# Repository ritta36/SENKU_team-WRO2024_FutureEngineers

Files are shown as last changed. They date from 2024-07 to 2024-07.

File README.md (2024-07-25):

<h1 style="background-color: rgba(200, 200, 200, 0.6)">SENKU-Team soulotion_Future Engineers WRO2024</h1>
<hr>

WRO

<p> We have solved the WRO2024 Future Engineers problem, and this repository details the development and design process of an autonomous vehicle created for participation in the WRO 2024 Future Engineers Category. The car represents a fusion of theoretical, mathematical, and mechanical engineering principles, combined with complex programming tasks and computer vision techniques. The repository provides a detailed explanation of the solution presented by the SENKU team. It includes all the steps we have undertaken in detail, along with the written codes, mechanical and electronic components used, and a comprehensive and detailed explanation of the algorithm. Additionally, it covers all the essential technical and mathematical fundamentals necessary to create the SENKU Robot vehicle and solve the problem, with the aim of providing a comprehensive information source for everyone.<p>

<p>Using this repository, a self-driving car can be built that is capable of completing three laps within the boundaries of the track, overcoming the obstacles present, and finally parking in a designated spot.<p>

## Content

* `t-photos` contains 2 photos of the team (an official one and one funny photo with all team members)
* `v-photos` contains 6 photos of the vehicle (from every side, from top and bottom)
* `video` contains two .md files with links to Youtube videos for each open challenge and obstacle challenge.
* `Engineering Journal` It includes a PDF file for documentation that contains a complete explanation of the solution, including descriptions of the components used, the algorithm, and more..
* `schemes` contains several schematic diagrams for electromechanical components used in the vehicle هn addition to the complete circuit schematic, it illustrates the components and how they connect to each other.
* `src` This directorycontain the codes used during the competition, as well as all other necessary codes for testing sensors, motors, and calibration.
* `models` is for the files for models used by 3D printers to produce the vehicle elements.
* `other` Here, we have included all the auxiliary folders that contain: flowcharts used for a clearer explanation of the followed algorithms, a pictures folder containing the images used in the repository, and finally, a <a href="https://github.com/ritta36/SENKU_team-WRO2024_FutureEngineers/blob/main/README.md#introduction">Software Setup.md</a> file that provides a comprehensive and sufficient explanation of how to set up the software, install necessary applications, download libraries, and more.
<h1>Introduction</h1>

<p1>The problem we have solved involves creating a self-driving car capable of completing laps within the boundaries of the track, overcoming colored obstacles based on their color, and finally parking in a designated area within the track. To achieve this, we used electronic components with functional capabilities that serve the solution, as well as mechanical techniques that aid in movement.

Regarding the codes, we used a Python code to capture images using a camera and process them to identify the locations and colors of the obstacles, and then send the information to the Arduino board. The Arduino board uses this information along with sensor readings, which are processed using Arduino C code, to control the motors' movements to correctly navigate the obstacles and complete the laps within the track.
This repository will explain the following:
<p1>

<h2>Contents of Readme file:</h2>

<dl>
  <dt><a href="https://github.com/ritta36/SENKU_team-WRO2024_FutureEngineers/blob/main/README.md#introduction">Introduction</a></dt>
  <dt><a href="https://github.com/ritta36/SENKU_team-WRO2024_FutureEngineers/blob/main/README.md#mobility-management">Mobility Management</a></dt>
  <dd><a href="https://github.com/ritta36/SENKU_team-WRO2024_FutureEngineers/blob/main/README.md#1-vehiclemainbody">-Vehicle Main Body</a></dd>
  <dd><a href="https://github.com/ritta36/SENKU_team-WRO2024_FutureEngineers/blob/main/README.md#2-motion-mechanism">-Motion Mechanism</a></dd>
  <dd><a href="https://github.com/ritta36/SENKU_team-WRO2024_FutureEngineers/blob/main/README.md#3-engineering-principles">-Engineering Principles</a></dd>

  <dt><a href="https://github.com/ritta36/SENKU_team-WRO2024_FutureEngineers/tree/blob/main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">Power and Sense Management</a></dt>
  <dd><a href="https://github.com/ritta36/SENKU_team-WRO2024_FutureEngineers/tree/blob/main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">-Electrical Parts</a></dd>
  <dd><a href="https://github.com/ritta36/SENKU_team-WRO2024_FutureEngineers/tree/blob/main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">-Overall Circuit Current Usage</a></dd>
  <dd><a href="https://github.com/ritta36/SENKU_team-WRO2024_FutureEngineers/tree/blob/main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">-Circuit Grounding</a></dd>
  <dd><a href="https://github.com/ritta36/SENKU_team-WRO2024_FutureEngineers/tree/blob/main?tab=readme-ov-file#4-power-supply">-Power Supply</a></dd>
  <dd><a href="https://github.com/ritta36/SENKU_team-WRO2024_FutureEngineers/blob/main/README.md#overall-scheme">-Overall Scheme</a></dd>
  
  <dt><a href="https://github.com/ritta36/SENKU_team-WRO2024_FutureEngineers/blob/main/README.md#obstacle-management">Obstacle Management</a></dt>
  <dd><a href="https://github.com/ritta36/SENKU_team-WRO2024_FutureEngineers/blob/main/README.md#1-open-challenge-algorithm">-Open Challenge Algorithm</a></dd>
  <dd><a href="https://github.com/ritta36/SENKU_team-WRO2024_FutureEngineers/blob/main/README.md#2-computer-vision">-Computer Vision</a></dd>
  <dd><a href="https://github.com/ritta36/SENKU_team-WRO2024_FutureEngineers/blob/main/README.md#3-image-processing">-Image Processing</a></dd>
  <dd><a href="https://github.com/ritta36/SENKU_team-WRO2024_FutureEngineers/blob/main/README.md#4-problems-we-encountered">-Problems We Encountered</a></dd>
  <dt><a href="https://github.com/ritta36/SENKU_team-WRO2024_FutureEngineers/blob/main/README.md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">Suggestions and Future Modifications</a></dt>
  <dd><a href="https://github.com/ritta36/SENKU_team-WRO2024_FutureEngineers/blob/main/README.md#1-open-challenge">-Open Challenge</a></dd>
  <dd><a href="https://github.com/ritta36/SENKU_team-WRO2024_FutureEngineers/blob/main/README.md#2-obstacle-challenge">-Obstacle Challenge</a></dd>
  <dd><a href="https://github.com/ritta36/SENKU_team-WRO2024_FutureEngineers/blob/main/README.md#3-differential">-Differential</a></dd>
  <dd><a href="https://github.com/ritta36/SENKU_team-WRO2024_FutureEngineers/blob/main/README.md#4-micro-controller-upgrade">-Micro-controller Upgrade</a></dd>
  <dd><a href="https://github.com/ritta36/SENKU_team-WRO2024_FutureEngineers/blob/main/README.md#5--sensor-upgrades">-Sensor Upgrades</a></dd>
  <dd><a href="https://github.com/ritta36/SENKU_team-WRO2024_FutureEngineers/blob/main/README.md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">-Power Management System (PMS)</a></dd>
  <dt><a href="https://github.com/ritta36/SENKU_team-WRO2024_FutureEngineers/blob/main/README.md#conclusion">Conclusion</a></dt>
  <dt><a href="https://github.com/ritta36/SENKU_team-WRO2024_FutureEngineers/blob/main/README.md#references">References</a></dt>
</dl>

<h2>Mobility Management</h2>

<h3>1-VEHICLEMAINBODY</h3>
<p>The main body of the vehicle was divided into two sections. The 3D printing section comprises four parts: the upper structure, two parts forming a camera holder, and the last part serving as a battery holder.<br> 
The second part of the structure is a chassis that features rear-wheel drive combined with a front steering mechanism, enabling it to turn both left and right. Also, it is made from aluminum which is a good material due to its lightness and durability.
The main microcontroller is an Atmega mounted on an Arduino Mega 2560 board. To ensure accurate and efficient control and direction of the vehicle’s movement, we employed several crucial components which are :
<br> • ServoMotorModel
<br> •  DC JSumo Motor 1000 RPM
<br> • BTSMotorDriver</p>
<p>The servo motor model was selected for controlling the vehicle’s steering, while the BTS7960 motor driver is utilized to control the movement of the DC motor, providing the necessary power to drive the vehicle’s motion.</p>

<h4>2-3D Printing parts</h4>
<p>We utilized SOLIDWORKS to design the components, followed by 3D printing these designs using PLA material. This process enabled us to create precise and customized parts for our robot, ensuring optimal performance and adherence to our design specifications. you can reach the 3D files in <a href="https://github.com/ritta36/SENKU_team-WRO2024_FutureEngineers/tree/main/models">this link.</a></p>

<b>Hexagonal Rod</b>
<p>The hexagonal rod is a key component, used for providing structural support in the assembly. It features a hollow center which allows for integration with other parts.</p>

<b>• Camera Holder</b>
<p>The camera holder is designed to securely hold the camera in place, ensuring stability and precision in positioning. It includes both parts of the holder and the complete assembly.</p>
<b>• Ultrasonic Sensor Holder Base</b>
<p>The ultrasonic sensor holder base is used to mount the ultrasonic sensor, providing a stable platform for accurate distance measurements.</p>
<b>• JSumo Tan Technic Gear 20 Tooth Double Bevel</b>
<p>This gear is a crucial component in the assembly, providing the necessary transmission of motion through its double bevel design.</p>
</li>
<b>• Battery Holder</b> The battery holder is designed to securely hold the battery in place, providing necessary power to the assembly. It is robustly built to ensure stability and easy replacement of batteries when needed.<br>
  <h3>3-Motion Mechanism.</h3>
  <p>We implemented Ackermann steering by installing a servo motor that allows the steering mechanism to operate freely. Additionally, a DC Jsumo motor with a 1000 rpm output acts as the propulsion motor. The kinetic energy produced by the Jsumo is conveyed to the rear wheels through a differential gearbox, and this energy is transmitted to the wheels via drive shafts constructed from LEGO components. Now we will explain both of the <b>Ackermann steering</b> and the <b>Differential gear:</b></p>
  <h4>1-Ackerman Steering Mechanism</h4>
  <p>Our design features an Ackermann steering mechanism, essential for providing efficient and responsive steering performance. The Ackermann steering principle is instrumental in minimizing tire wear and enhancing the vehicle's handling, especially during turns.</p>
   <p>The key features and benefits of the Ackermann steering is that it enhances maneuverability by reducing tire slippage during turns. This is achieved by configuring the steering linkages to allow the inner wheel to turn at a sharper angle than the outer wheel. Each wheel follows its own natural arc around the corner, leading to more precise steering and better vehicle control. Additionally, the Ackermann steering mechanism streamlines the overall design of the steering system. It eliminates the need for complex gear arrangements, which reduces weight and potential failure points within the system. This simpler design also leads to easier maintenance and lower manufacturing costs.</p>

<b>Working Mechanism of Ackermann Steering: </b>
<p>The functionality of the Ackermann steering system can be summarized as follows:</p>
<b>Steering Input Translation:</b> When the servo motor is activated, the input is conveyed through the steering linkage to both front wheels. The unique angles and lengths of the steering arms cause the inner wheel to turn more sharply than the outer wheel.<p>
<p><b>Cornering:</b> During cornering, the Ackermann geometry ensures that each wheel follows its respective path, minimizing slippage and enhancing the vehicle's grip on the playing field.</p>
<b>Key Parameters of Ackermann Steering</b>

<p><b>Steering Ratio:</b> In the Ackermann steering system, the steering ratio describes the relationship between the rotation of the servo angle and the resulting rotation of the wheels. It can be expressed mathematically as follows:</p>
<p>Steering Ratio = <span>&theta;<sub>Servo angle</sub></span> / <span>&theta;<sub>wheels</sub></span></p>

<p>A higher steering ratio means that a smaller rotation of the servo angle results in a larger rotation of the wheels, providing greater turning capability. Conversely, a lower steering ratio requires more rotation of the servo to achieve the same amount of wheel rotation, resulting in a less sensitive steering response.</p>
<b>Servo Motor Torque</b>
<p>Steering torque (T<sub>servo</sub>) is the force applied to the servo as a result of the torque output from the steering system. It is calculated by multiplying the applied force by the effective lever arm length (L<sub>eff</sub>):</p>
<p><strong>T<sub>servo</sub> = F<sub>steering</sub> × L<sub>eff</sub></strong></p>
<p>Higher servo motor torque indicates that more force is needed to turn the wheels, providing greater resistance to steering and a more stable driving experience.</p>
<b>Steering Wheel Angle</b>
<p>The steering wheel angle refers to the angular displacement of the steering wheel from its neutral position. This angle determines the orientation of the vehicle's steering mechanism and, consequently, its direction of movement:</p>
<p><strong>&theta;<sub>servo</sub> = &theta;<sub>servo angle</sub> × Steering Ratio</strong></p>
<p>Servo motor angle directly influences the turning radius of the vehicle, affecting its maneuverability and handling characteristics.</p>

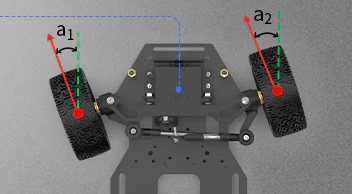
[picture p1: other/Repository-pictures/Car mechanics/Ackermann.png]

<br> 
    <figcaption>Figure 20: Ackermann steering principle.</figcaption>
  </figure>

<br> 
<br>
<h4>2-Differential Gear</h4>

<h4>Current Implementation and Challenges</h4>

<p>The differential gear is a vital component in our robot, ensuring that the rear wheels can spin at different rates while maintaining balanced power distribution. This mechanism is particularly crucial during turns or when traction varies between the two wheels, allowing for smooth and controlled movement. Here’s an overview of the differential gear system and its components:</p>

<strong>Components:</strong>
<ol>
    <li><strong>Ring Gear:</strong> This large gear, attached to the axle shaft, receives power from the engine or driveshaft.</li>
    <li><strong>Pinion Gear:</strong> A smaller gear that connects to the drive shaft and meshes with the ring gear.</li>
    <li><strong>Side Gears:</strong> Two gears that link the differential to the axle shafts.</li>
    <li><strong>Spider Gears:</strong> Positioned between the side gears, these gears permit the wheels to rotate at varying speeds.</li>
</ol>
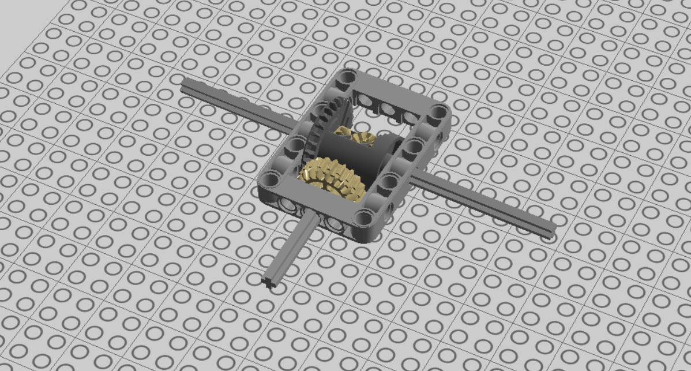
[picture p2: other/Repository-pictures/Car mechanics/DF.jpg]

<figcaption>Figure 21: Lego Differential Gear</figcaption>
</figure>
<br>
<br>
<strong>Functionality:</strong>
<p>When the vehicle travels in a straight line, the differential distributes torque equally to both wheels. During a turn, the inside wheel (closer to the center of the turn) needs to rotate slower than the outside wheel to prevent slippage. The differential achieves this by allowing the side gears to rotate at different speeds while still distributing power effectively.</p>

<strong>Calculating Gear Ratio:</strong>
<p>Before designing a differential gear, determining the gear ratio is crucial. This involves understanding the motor specifications and the differential’s mechanical setup. The gear ratio can be calculated by counting the teeth on the ring gear and the side gears:</p>

<p>$$ \text{GR} = \frac{R}{S1 + S2} $$</p>

<p>Where:</p>
<ul>
    <li><code>R</code> is the number of teeth on the ring gear.</li>
    <li><code>S1</code> and <code>S2</code> are the number of teeth on each side gear.</li>
</ul>

<p>This ratio indicates the rotational speed and torque distribution between the two side gears of the differential. Once calculated, this ratio helps relate the motor speed to the wheel speed. The wheel speed N<sub>wheel</sub> can be derived from the motor’s no-load speed <sup>N<sub>Motor, no-load</sub> using the formula:</p>

<p> $$ N_{\text{wheel}} = \frac{N_{\text{Motor, no-load}}}{\text{GR}} $$ </p>

<p>The wheel speed reflects the rotational speed of the differential’s side gears, directly influencing the vehicle’s speed. While theoretical calculations provide a baseline, real-world values often require calibration due to various unaccounted constraints.</p>

<h4>Suggestions and Future Modifications</h4>

<strong>Current Differential Issues:</strong>
<p>In our current design, we utilized a LEGO differential; however, we observed several shortcomings, specifically its low durability and the high flexibility of the LEGO axles.</p>

<strong>Recommended Differential Upgrade:</strong>
<p>To enhance the vehicle’s performance, we recommend using a metal differential with metal axles, which offer greater durability and reduced flexibility. This upgrade will ensure:</p>
<ul>
    <li><strong>Increased Durability:</strong> Metal differentials are more robust and can withstand higher stress and load without failing, ensuring longer operational life and reliability.</li>
    <li><strong>Reduced Flexibility:</strong> Metal axles are less flexible compared to LEGO axles, resulting in more precise and consistent power transmission to the wheels, improving overall vehicle control.</li>
</ul>

<strong>Impact on Vehicle Performance:</strong>
<ul>
    <li><strong>Enhanced Stability:</strong> The reduced flexibility and increased robustness of the metal components will provide greater stability, particularly during turns and when navigating uneven terrain.</li>
    <li><strong>Improved Power Transmission:</strong> The precise and consistent power transmission afforded by metal axles will enhance the vehicle’s responsiveness and maneuverability.</li>
    <li><strong>Long-Term Reliability:</strong> The durability of metal differentials ensures that the vehicle can operate under demanding conditions without frequent maintenance or replacement of parts.</li>
</ul>

<p>Implementing these modifications will significantly improve the vehicle's performance, making it more reliable and efficient in navigating the challenges of the competition.</p>

<h4> 3-Motor Driver</h4>
<p>A motor driver is an indispensable device in controlling motors because it allows the safe handling and delivery
of required power for driving the motor; at the same time, it includes protection features to guard against
damage under abnormal operating conditions. In addition, the motor driver provides accurate control, speed,
direction, and acceleration. A driver is a must for those applications that require precise positioning or motion
control, as in our case. It has bidirectional control, works with various motor types, and optimizes power usage
for more efficiency</p>

<figure>

  <br>
<figure >Figure 4: Basic-open loop control of motor speed</figcaption>
</figure>
<br>
<br> 

<h4>4- Wheels</h4>
<p>Wheels were used in the robot's design, their advantage comes from their efficiency and light weight. These wheels provide good friction, which enhances stability and maneuverability on various surfaces. [26]</p>
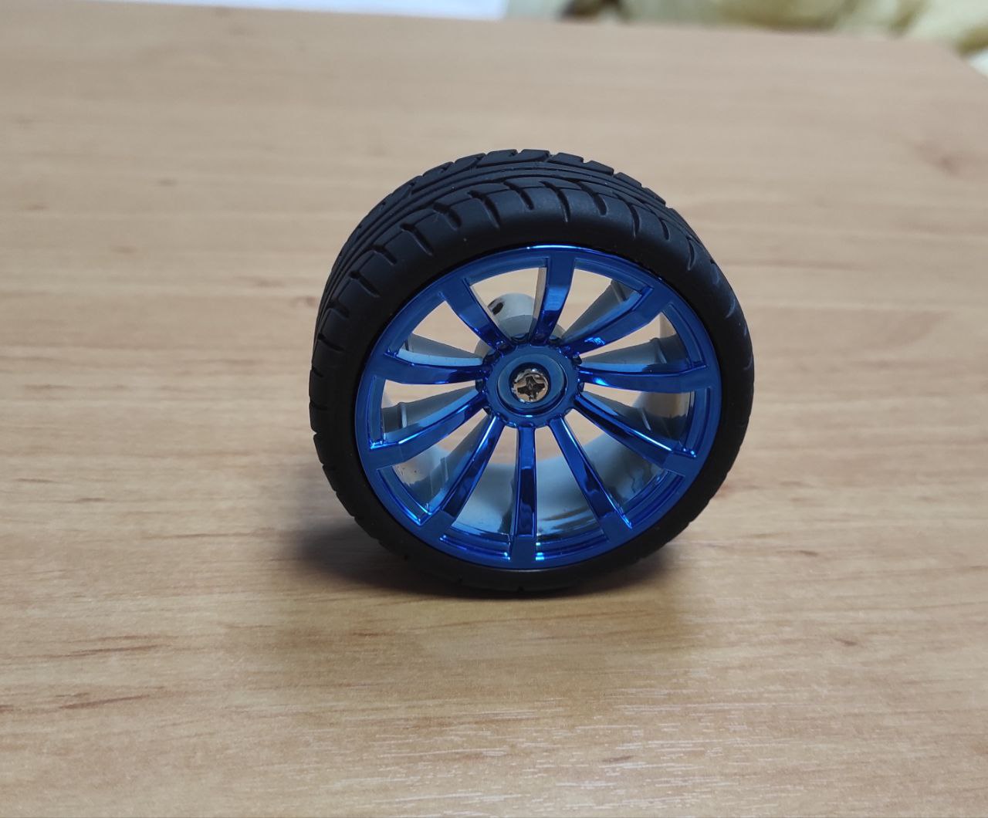
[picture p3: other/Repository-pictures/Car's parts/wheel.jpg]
Rubber Wheel

<caption><strong>Figure 23:</strong> Wheel</caption>
<table>
    <caption>Table 1: Specifications of 65mm Rubber Wheels</caption>
    <tr>
        <th>Specification</th>
        <th>Details</th>
    </tr>
    <tr>
        <td>Diameter</td>
        <td>65mm</td>
    </tr>
    <tr>
        <td>Width</td>
        <td>25-30mm</td>
    </tr>
    <tr>
        <td>Material</td>
        <td>Rubber tire with plastic or metal hub</td>
    </tr>
    <tr>
        <td>Axle Hole</td>
        <td>Compatible with standard hex couplings (often 4mm or 6mm)</td>
    </tr>
    <tr>
        <td>Coupling Type</td>
        <td>Lengthen copper coupling with hex connection</td>
    </tr>
    <tr>
        <td>Weight</td>
        <td>Usually light, suitable for small to medium-sized RC vehicles</td>
    </tr>
    <tr>
        <td>Use</td>
        <td>Suitable for DIY projects, Arduino smart car chassis, and other robotics applications</td>
    </tr>
</table>

<h4>5- Lego Axles</h4>
<p>Using the LEGO axles (4.8mm Diameter) on both the differential gears mechanism and the wheels connecting leads to a significant improvement in the robot's efficiency. The axles deliver accurate rotary motion while cutting down friction and energy losses. It is made of PA (Polyamide), which is a type of material that can withhold high loads and impacts. This means it is suitable for elements that have to be tough and can interact with each other, thus enabling a smooth power transmission of prolonged operation.</p>
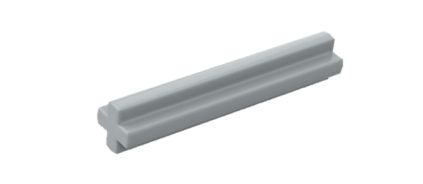
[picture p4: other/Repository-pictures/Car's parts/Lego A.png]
Lego Axle

<caption><strong>Figure 24:</strong> Lego Axle</caption>

<h3>3-Engineering Principles</h3>
  <p>The selection of materials and components for our vehicle was guided by several key engineering principles:</p>
  <ul>
    <li><strong>Torque and Speed Calculations:</strong> The motors were chosen based on the required torque to overcome friction and inertia, ensuring sufficient speed for the competition.</li>
    <li><strong>Material Selection:</strong> Aluminum was selected for its strength-to-weight ratio, providing a lightweight yet durable structure.</li>
    <li><strong>3D Printing Selection:</strong> PLA is easy of Printing, Strength and aligns with sustainable engineering practices, making it an eco-friendly choice.</li>
    
  </ul>
<h2>Power and Sense Management</h2>

 <h3>1-Electrical Parts</h3>
    <section>
        <b>Section 2, Subsection 1</b>
        <ol>
            <li>
                <strong>Arduino Mega 2560:</strong>
                <ul>
                    <li>Microcontroller: ATmega2560</li>
                    <li>Features: 54 digital I/O pins, 16 analog inputs, USB interface, operates at 5V</li>
                    <li>Used for complex and resource-intensive projects due to ample processing power and memory.</li>
                </ul>
            </li>
            <li>
                <strong>Arduino Sensor Shield v2.0:</strong>
                <ul>
                    <li>Designed for Arduino Mega 2560</li>
                    <li>Features: Easy connection for sensors and modules, supports I2C, UART, and analog interfaces</li>
                    <li>Provides convenience and flexibility in connecting multiple components to the Arduino board.</li>
                </ul>
            </li>
            <li>
                <strong>Raspberry Pi 4 Model B:</strong>
                <ul>
                    <li>Processor: Broadcom BCM2711, quad-core Cortex-A72</li>
                    <li>Features: Dual micro HDMI ports, wireless LAN, Bluetooth 5.0, USB 3.0, up to 8GB RAM</li>
                    <li>Suitable for projects requiring substantial processing power and connectivity.</li>
                </ul>
            </li>
            <li>
                <strong>Cooling Fan:</strong>
                <ul>
                    <li>Used to reduce overheating in Raspberry Pi and enhance CPU performance</li>
                    <li>Essential for maintaining optimal operating temperatures and prolonging the lifespan of the device.</li>
                </ul>
            </li>
            <li>
                <strong>Raspberry Camera Module 3 (75 degrees FoV):</strong>
                <ul>
                    <li>Sensor: Sony IMX708, 11.9 Megapixels</li>
                    <li>Features: Motorized focus, wide field of view suitable for detecting obstacles and ensuring effective image processing.</li>
                </ul>
            </li>
            <li>
                <strong>BTS7960 Motor Driver:</strong>
                <ul>
                    <li>H-Bridge configuration, supports motors between 5V and 27V</li>
                    <li>Features: current sensing and protection against overcurrent and overtemperature</li>
                    <li>Useful in robotics for precise motor control.</li>
                </ul>
            </li>
            <li>
                <strong>XL4005 DC-DC Step-Down Converter:</strong>
                <ul>
                    <li>Input: 5V to 32V, Output: Adjustable from 0.8V to 30V, up to 5A current</li>
                    <li>High efficiency and includes features like thermal shutdown and short circuit protection</li>
                    <li>Converts high voltage to a lower voltage while maintaining high efficiency.</li>
                </ul>
            </li>
            <li>
                <strong>TowerPro MG996R Servo:</strong>
                <ul>
                    <li>High torque with metal gears, operates from 4.8V to 7.2V</li>
                    <li>Provides precise control suitable for robotics applications requiring robust actuation.</li>
                </ul>
            </li>
            <li>
                <strong>Li-Poly RC Battery:</strong>
                <ul>
                    <li>11.1V, 2700mAh with a 35C discharge rate</li>
                    <li>Provides high power and efficiency for demanding applications like RC vehicles.</li>
                </ul>
            </li>
            <li>
                <strong>JSumo 1000 RPM Motor:</strong>
                <ul>
                    <li>12V operation, 1000 RPM no-load speed</li>
                    <li>High power motor, ideal for robotics and sumo robot competitions.</li>
                </ul>
            </li>
            <li>
                <strong>MPU-6050 Sensor:</strong>
                <ul>
                    <li>Combined 3-axis gyroscope and accelerometer</li>
                    <li>Useful for motion sensing and orientation tracking in robotics.</li>
                </ul>
            </li>
            <li>
                <strong>HC-SR04 Ultrasonic Sensor:</strong>
                <ul>
                    <li>Measures distance using ultrasonic waves</li>
                    <li>Employed in robotics for obstacle detection and navigation.</li>
                </ul>
            </li>
        </ol>
    </section>

<h3> 2-Overall Circuit Current Usage</h3>
 <p> here are many reasons why it is important to have an accurate knowledge of the electrical component requirements which include</p>
    <ol>
        <li>
            <strong>Dual Mode (Operational and Sleep):</strong>
            <p>The power supply system is programmed to handle different current requirements when the robot is active (Operational) and when it is in a power-saving mode (Sleep). This helps in ensuring that the robot operates efficiently without draining unnecessary power when not performing intensive tasks.</p>
        </li>
        <li>
            <strong>Optimize for Battery Life:</strong>
            <p>Understanding the power consumption of each component is essential for optimizing battery life. By analyzing the current draw in various operational states, strategies can be developed to extend battery life, such as selecting the appropriate batteries and implementing power-saving modes.</p>
        </li>
        <li>
            <strong>Heat Management:</strong>
            <p>The total current load on a circuit contributes to the amount of heat generated by electrical components. Knowing this helps in designing effective cooling measures, which are crucial for preventing overheating that could lead to performance degradation or hardware damage.</p>
        </li>
        <li>
            <strong>Safety:</strong>
            <p>Accurate knowledge of the maximum current that each component draws is essential for designing a safe electrical system. This includes ensuring that all components can handle the peak currents under load without risk of electrical failures or hazards.</p>
        </li>
        <li>
            <strong>Cost Efficiency:</strong>
            <p>By understanding the exact power needs of each component, more cost-effective components and systems that meet the necessary specifications without excess can be selected.</p>
        </li>
    </ol>

<h3>3-Circuit Grounding</h3>
    <p>Circuit grounding connects all components with a common ground, providing a reference point for all voltages in the circuit and dramatically simplifying the measurement of voltage at any point in the circuit. It ensures the signal moves accurately without distortion, prevents electrical shocks, and safeguards the equipment, as well as people, from hazards that can arise otherwise.</p>
    <p>Grounding reduces electromagnetic interference (EMI) and radio frequency interference (RFI) by allowing a path for unwanted currents to dissipate harmlessly into the ground. This can greatly improve the performance and overall reliability of the circuit. Grounding stabilizes the voltage levels, preventing voltage fluctuation by ensuring a consistent electrical potential across all components. It may also help in reducing some noise and interference within the circuit. When several sections of the circuit share a common reference point, one can better filter noise and interference.</p>

  <h3>4-Power Supply</h3>
    <p>In the revised setup, an 11.1V – 2700mAh 35C Li-Poly RC battery is used as the power source, which directly provides 11.1V to both the BTS motor driver and the RioRand step-down DC-DC converter. The converter adjusts the voltage from 11.1V down to 5V to power the Arduino board. Additionally, the Arduino Sensor Shield, which conveniently offers the GND and VCC pins for connecting ultrasonic sensors, a servo motor, and a gyroscope without the need for a bridge or extra pins. This configuration results in a visually pleasing circuit that provides easy access to all pins and simplifies the troubleshooting of faults and issues. The DC motor receives power directly from the battery through the BTS motor driver, maintaining the supply at 11.1 volts.</p>

  <h3>5-Overall Scheme</h3>
    <p>Due to the large number of electronic components used in our circuit, we utilized a special power supply distribution using basic electronic components. The description below provides an overview of the electrical design:</p>
 
<br>
<br>
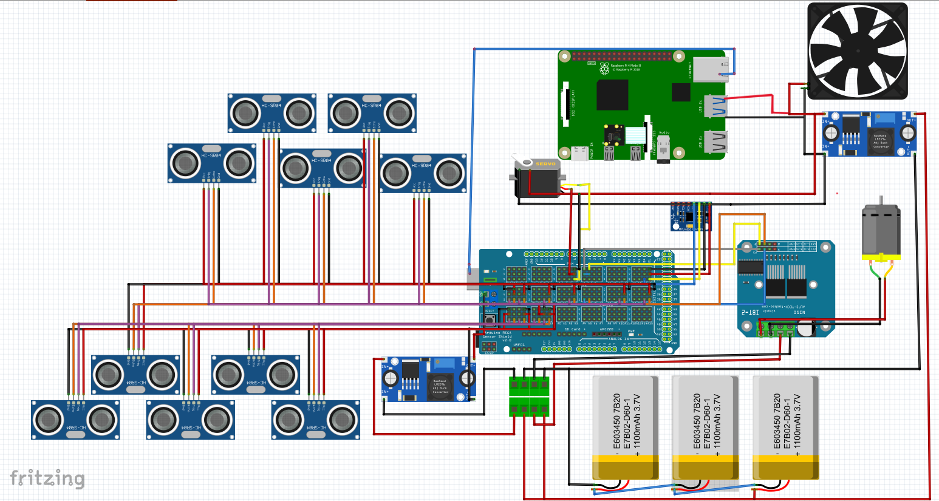
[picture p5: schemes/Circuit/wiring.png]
wiring managment

<caption><strong>Figure 25:</strong> The Circuit Wiring.</caption>
<br>
<br>
<br> 
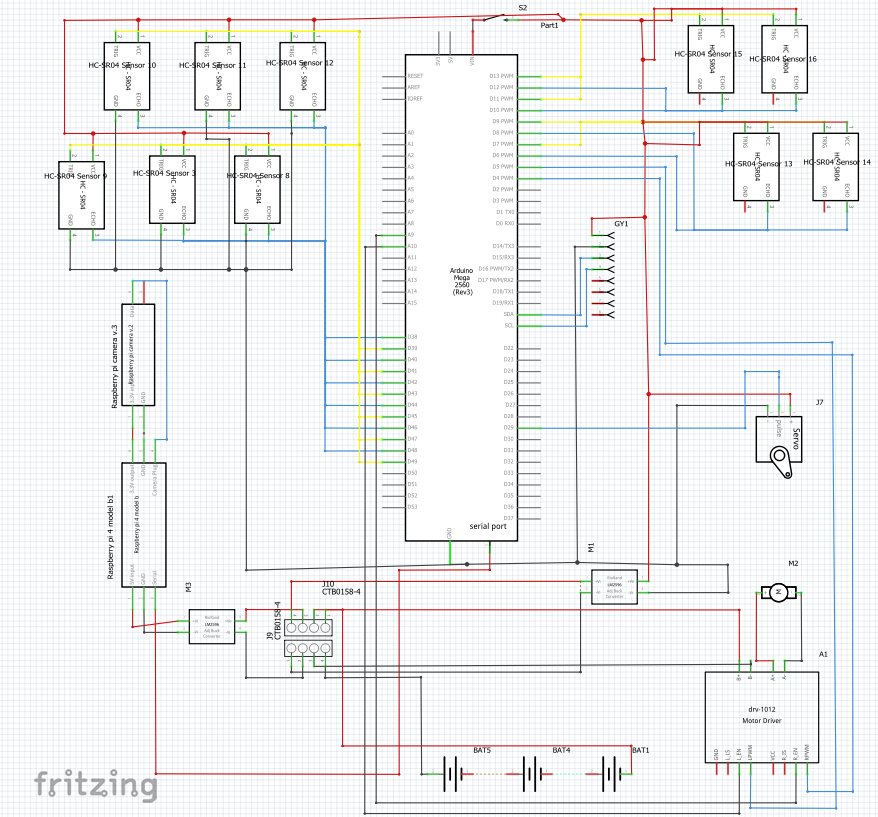
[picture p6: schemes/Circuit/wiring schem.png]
wiring schem

<br>
<caption><strong>Figure 26:</strong> The Circuit Wiring Diagram.</caption>
<br>

<h2>Obstacle Management</h2>

<h3>1-Open Challenge Algorithm</h3>
<p>In this section, we detail our approach for the Open Challenge, where the goal is to complete three laps while avoiding collisions with the track walls and achieving the fastest possible time. Our strategy involves designing a robust algorithm that ensures precise navigation and smooth transitions between different segments of the track. The track is divided into two primary zones: the Safe Zone and the Danger Zone, each requiring distinct handling strategies.</p>
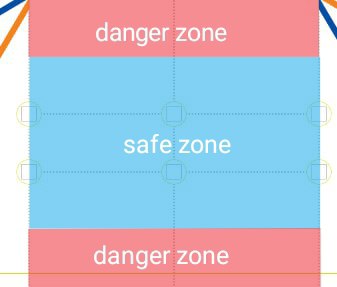
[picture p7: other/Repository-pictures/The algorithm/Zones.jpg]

<figcaption>Figure 27: zones Division
</figcaption>
</figure>
<h4> Safe Zone Navigation</h4>
<p>In the Safe Zone, the robot can move safely without the risk of colliding with the wall. The robot should maintain a straight path parallel to the wall. This is managed using a PD (Proportional-Derivative) controller that keeps the robot's angle constant. The gyroscope readings are used as inputs to the algorithm, and the setpoint is adjusted after each turn. The PD controller formula used is:</p>
<pre>PIDOutput = K_p &times; Error_t + (Error_t - Error_{t-1}) / IntervalLength &times; K_d</pre>
<p>Where:</p>

  <li><i>Error_t = GyroscopeReading - SetPoint</i></li>

<h4> Danger Zone Handling</h4>
<p>When the robot enters the Danger Zone, immediate corrective action is required to move it back to the Safe Zone. For this, we employ a P (Proportional) controller with a high proportional gain:</p>
<pre>ServoAngle = K_p &times; (D_{vertical} - D_{unprotected})</pre>
<p>Where:</p>

  <li><i>D_{vertical} = cos(Angle) &times; DS1 + DS2 / S2</i></li>

<h4> Turn Detection and Direction Control</h4>
<p>The robot detects turns at distances greater than 100 cm. If it cannot align parallel to the wall, incorrect ultrasonic readings might occur. In such cases, the robot uses its front ultrasonic sensor to detect the front wall and, if a safe turn is not possible, it moves backward until a safe turn can be made. The robot determines the movement direction (clockwise or counterclockwise) based on which side the turn is detected.</p>

<p>Overall, this algorithm ensures the robot navigates efficiently through the track, handling turns and zones with precise control to achieve the fastest lap times possible.</p>

<figcaption>Figure 28: Open challenge flowchart
</figcaption>
</figure>

<hr>

  <h3>2-Computer Vision</h3>
    <p>Computer vision is a fundamental technology in robotics and automation, crucial for enabling self-driving cars to perceive and interpret their surroundings. In our project, computer vision (CV) techniques empower the robotic system to gather essential information, facilitating informed decision-making and immediate actions. The identification of the pink
 parking, red and green pillars is critical for collision avoidance and maintaining a clear path for the robot.</p>
    
   <p>We employ the HSV (Hue, Saturation, Value) color space for color detection due to its robustness under varying lighting conditions. Unlike other color spaces such as RGB (Red, Green, Blue) or HSL (Hue, Saturation, Lightness), HSV separates color information (hue) from luminance, enhancing its reliability.</p>
    
  <b>HSV Color Space</b>
    <ul>
        <li><strong>Hue:</strong> Represents the type of color, measured as an angle in degrees (0-360), where red = 0, green = 120, blue = 240.</li>
        <li><strong>Saturation:</strong> Indicates the vibrancy of the color, ranging from 0 (gray) to 100 (full color).</li>
        <li><strong>Value:</strong> Defines the brightness of the color, with 0 as black (no brightness) and 100 as fully bright.</li>
    </ul>
    
  <b>Advantages of HSV over RGB for Color Detection</b>
    <ul>
        <li><strong>Decomposition of Color and Luminance:</strong> HSV effectively separates hue from saturation and value, making hue less affected by lighting changes and enabling more accurate region detection. RGB combines intensity with colors, complicating the appearance of hues under varying light.</li>
        <li><strong>Improved Color Filtering:</strong> HSV filters colors based on human perception, making it easier to isolate specific hues. In contrast, RGB colors can vary significantly with brightness changes.</li>
        <li><strong>Lighting Robustness:</strong> HSV is more resilient to lighting variations, as changes in light intensity affect hue less than in RGB, allowing for consistent color matching.</li>
    </ul>

   <p>Using HSV for computer vision in our project enhances the accuracy and reliability of color detection, crucial for the robot's autonomous navigation and obstacle avoidance.</p>
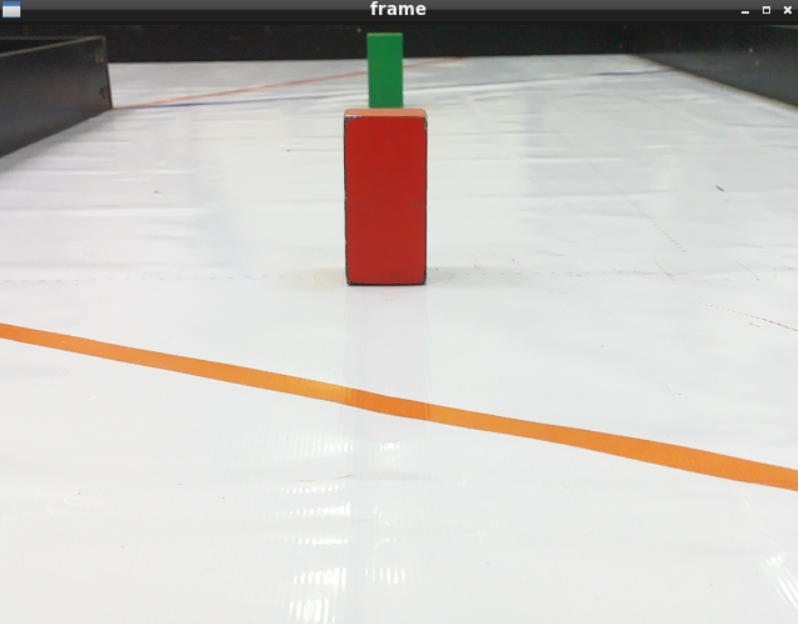
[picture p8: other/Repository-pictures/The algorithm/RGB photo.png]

<br>
<figcaption>Figure 29: RGB photo 
</figcaption>
</figure>
<br>
<br>
  <br> 
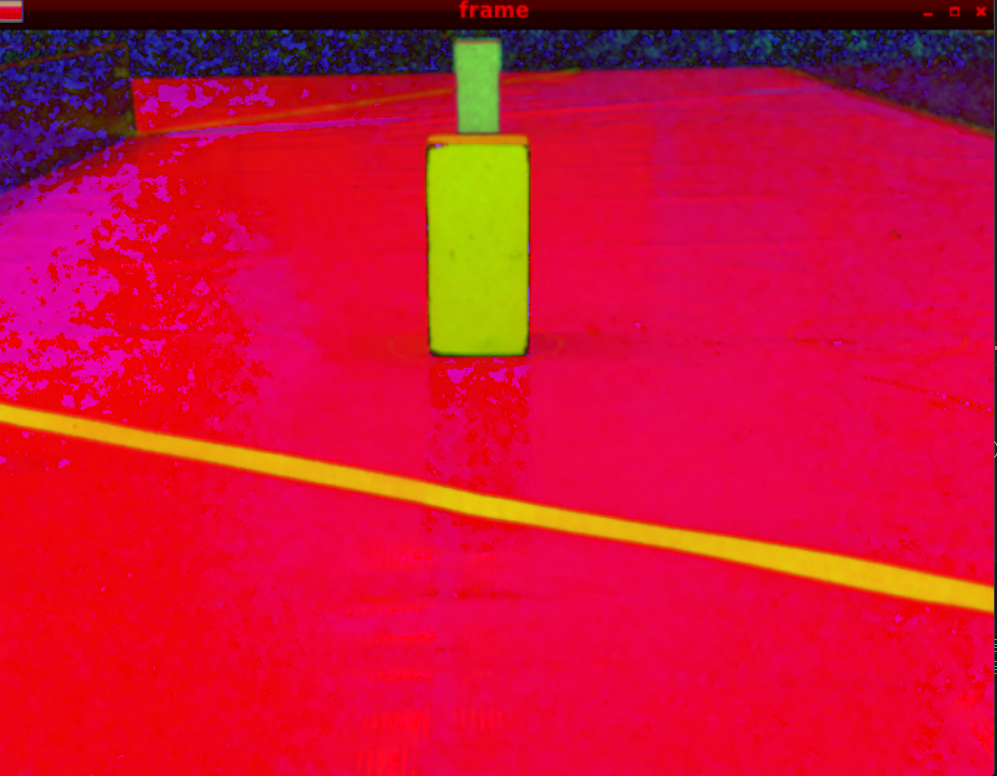
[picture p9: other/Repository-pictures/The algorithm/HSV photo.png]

<br>
<figcaption>Figure 30: HSV photo
</figcaption>
</figure>
<br>
<br>
<br>

<h3>3-Image Processing</h3>

  <h4>Setting the Camera Properties</h4>
    <p>The camera's shutter speed is adjusted according to the ambient lighting conditions. Shutter speed defines the duration for which the camera’s shutter remains open, allowing light to reach the camera sensor. In high-brightness environments, we reduce the shutter speed to limit the amount of light hitting the sensor during the calibration of HSV values. Conversely, in low-light conditions, we increase the shutter speed to allow more light to reach the sensor.</p>

  <h4>Pre-Processing</h4>
    <p>Pre-processing is essential before isolating the pillars to extract information. This step involves cleaning the captured images to remove unwanted artifacts, ensuring more accurate and reliable segmentation results. Cropping the frame removes distracting elements that might be mistaken for pillars.</p>

  <h4>Masking</h4>
    <p>To isolate specific colors, the image is first converted from the BGR color space to the HSV color space. We then identify the upper and lower HSV values of the target colors (red, green, or pink). Each pixel in the HSV frame is examined to determine if it falls within the specified color range. If it does, the corresponding pixel value in the mask will be white; otherwise, it will be black. The resulting mask frame will display white pixels for the desired color range and black pixels for all other colors.</p>

  <p>Our HSV values:</p>
    <ul>
        <li><strong>Red1:</strong> Lower value: [], Upper value: []</li>
        <li><strong>Red2:</strong> Lower value: [], Upper value: []</li>
        <li><strong>Green:</strong> Lower value: [], Upper value: []</li>
        <li><strong>Pink:</strong> Lower value: [], Upper value: []</li>
    </ul>
    <p>Note: HSV values may vary under different lighting conditions.</p>

| Original Frame | Mask | Result |
|---|---|---|
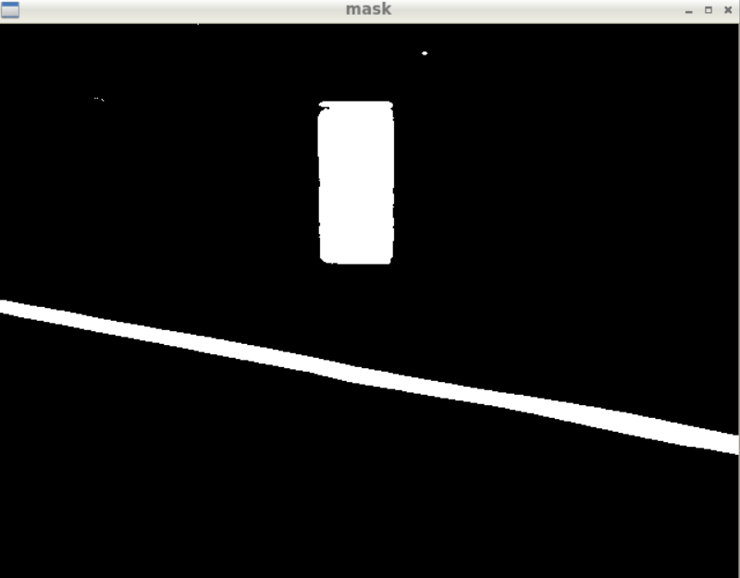
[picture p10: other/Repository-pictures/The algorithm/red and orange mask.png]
Mask Red 1
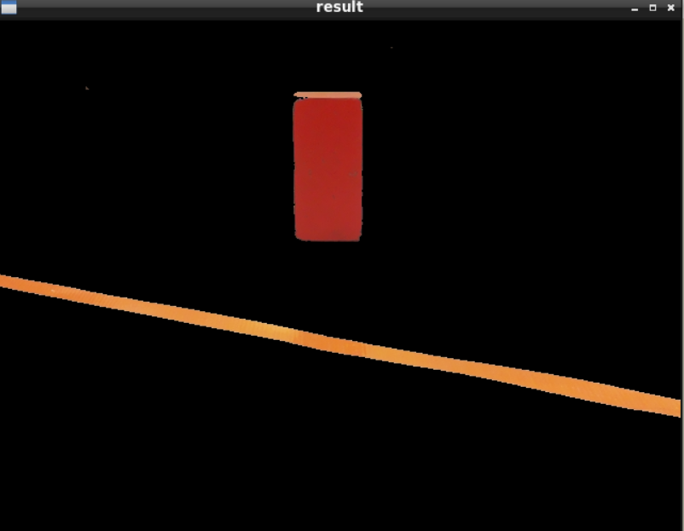
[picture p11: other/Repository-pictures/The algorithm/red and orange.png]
| Original Frame Red 1 |  |  |
| **Original Frame** | **Mask** | **Result** |
| **Figure 31: Red 1 Mask Analysis** |

| Original Frame | Mask | Result |
|---|---|---|
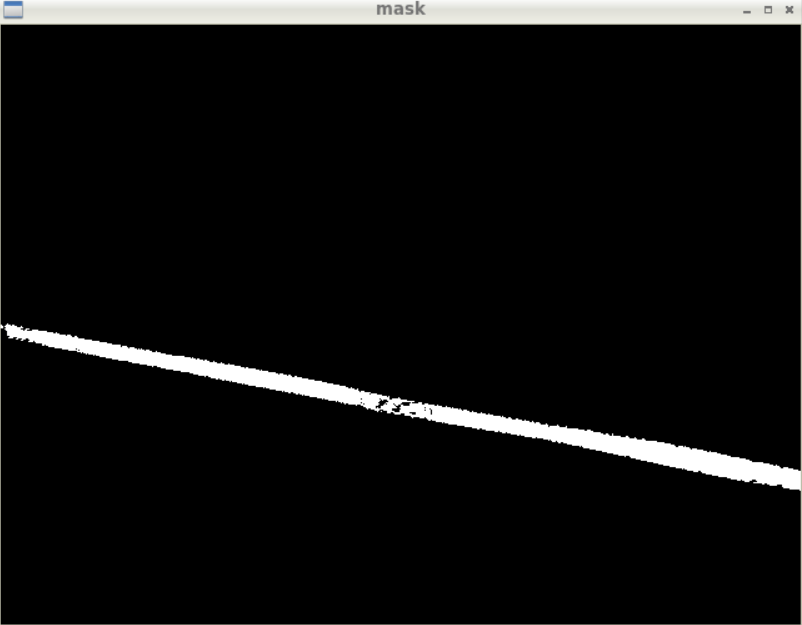
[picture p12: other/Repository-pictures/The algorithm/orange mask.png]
Mask Red 1
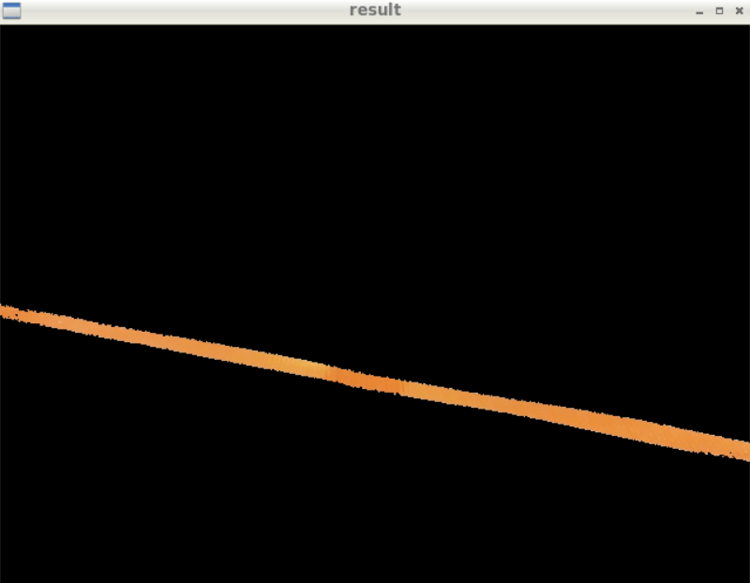
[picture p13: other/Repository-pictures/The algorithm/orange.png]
| Original Frame Red 2 |  |  |
| **Original Frame** | **Mask** | **Result** |
| **Figure 32: Red 2 Mask Analysis** |

| Original Frame | Mask | Result |
|---|---|---|
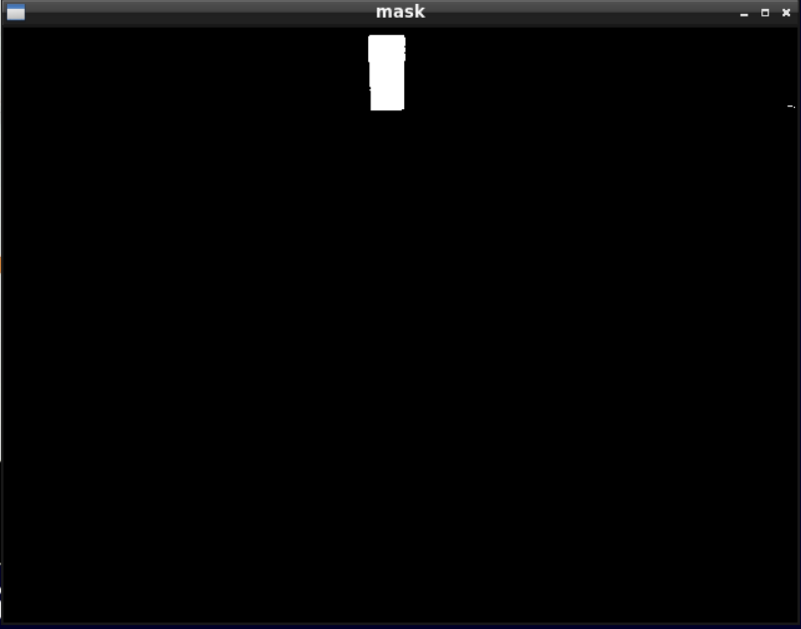
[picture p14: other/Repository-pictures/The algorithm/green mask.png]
Mask Red 2
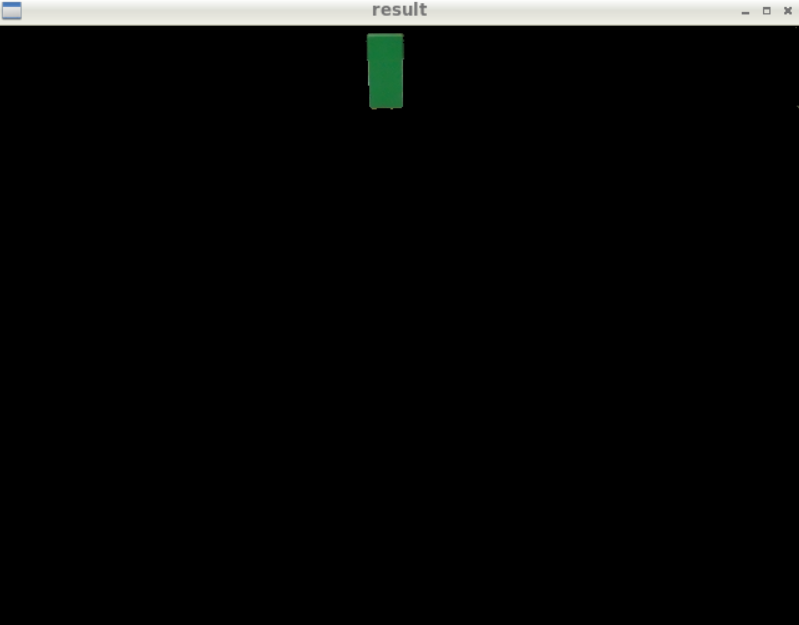
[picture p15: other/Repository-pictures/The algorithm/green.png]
Result Red 2
| Original Frame Green |  |  |
| **Original Frame** | **Mask** | **Result** |
| **Figure 33: Green Mask Analysis** |

  <h4>Contouring</h4>
    <p>Contour detection is the process of identifying the boundaries or edges of objects within an image. This process is fundamental to many image analysis applications, including image segmentation, object recognition, and classification.</p>
    <br>
<br>
<figcaption>Figure 34: Contouring Process
</figcaption>
</figure>
<br>
<br>

   <p><strong>Steps in the Contouring Process:</strong></p>
    <ol>
        <li>Finding the Contour Area:
            <pre>cv2.contourArea(contour)</pre>
        </li>
        <li>Finding the Bounding Rectangle:
            <pre>cv2.boundingRect(contour)</pre>
        </li>
        <li>Finding the Moment:
            <pre>cv2.moments(contour)</pre>
        </li>
        <li>Calculating Distance: The distance is calculated using a formula derived by plotting a curve between the actual distance and the contour area.</li>
    </ol>
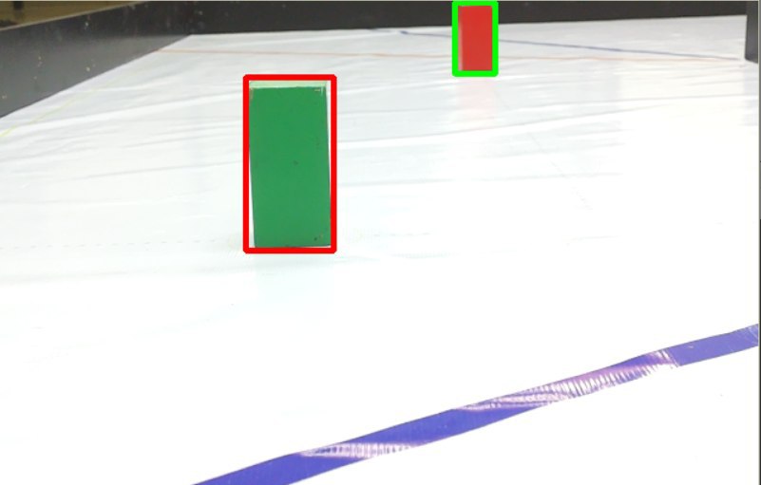
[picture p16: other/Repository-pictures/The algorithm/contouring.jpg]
Contouring Analysis

<strong>Figure 30: Contouring Analysis</strong>

  <h4>Our Algorithm to Avoid the Pillars</h4>
    <p>At the start of each section, the Raspberry Pi captures an image using the camera. It processes the image and applies a mask to detect any pillars in front of the vehicle. If a pillar is detected and the distance is less than 50 cm, the Raspberry Pi sends a signal to the Arduino ('G' for a green pillar, 'R' for a red pillar, and 'N' for no pillar). The Arduino then decides the course of action: turn left for 'G', turn right for 'R', or move forward for 'N'.</p>

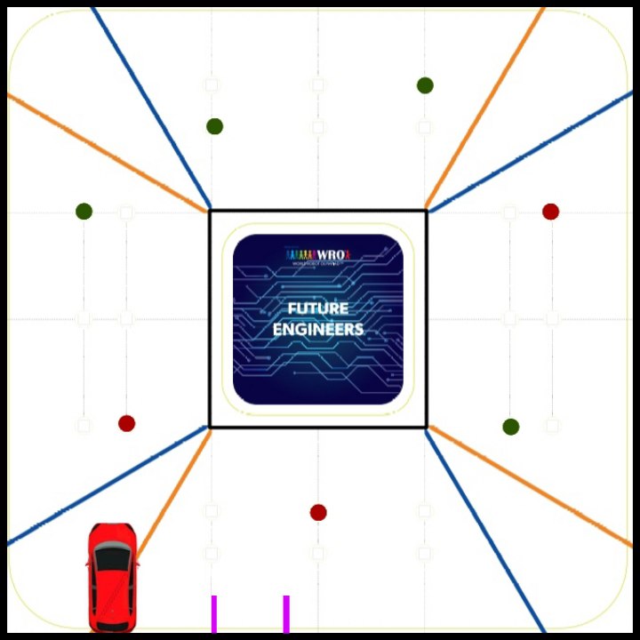
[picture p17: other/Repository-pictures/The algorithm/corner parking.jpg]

<br>
<figcaption>Figure 32:  the vehicle parking in the corner
</figcaption>
</figure>
<br>
<br>

<p>When the vehicle reaches a corner, the Arduino determines the direction of movement and communicates this to the Raspberry Pi ('L' for counterclockwise and 'R' for clockwise). At the end of each section, the Arduino sends a 'Hello' message to the Raspberry Pi, prompting it to take an image, process it, and report the current status back to the Arduino. The possible status cases are GG, G, RR, R, RG, and GR.</p>

<h3>4-Problems We Encountered</h3>

  <h4>Wave Interference</h4>
    <p>When two sensors on the same side of the robot operate simultaneously, the sound waves they emit can interfere with each other. To address this issue, we implemented a method where only sensors on opposite sides operate at any given time while the other sensors are disabled. Specifically, we take readings sequentially from R1 and L2, then R2 and L1, followed by F and B. This approach prevents wave interference during distance measurements.</p>

  <h4>Small Turn Angle and Sliding</h4>
    <p>Initially, the robot experienced issues with a small turn angle and sliding, primarily due to the absence of a differential gear. This caused the robot to require a large distance to achieve the desired turn angle, and the front tires often slipped. We resolved these problems by integrating a differential gear, which enhanced the turning capability and stability of the robot.</p>

  <h4>Flickering</h4>
    <p>Flickering refers to the visible fluctuation in brightness or color in video frames, which can occur rapidly and intermittently. We encountered this issue with the Raspberry Pi 4 and Camera Module 3 setup. Flickering can make the video output appear unstable and less effective for its intended use. We resolved this by adjusting the camera's shutter speed:</p>

   <pre>picam2.set_controls({"ExposureTime": shutter_speed})</pre>

  <p>This adjustment stabilized the video output, ensuring reliable performance for image processing tasks.</p>

  <h2> Suggestions and future modifications</h2>

  <h3>1-Open Challenge</h3>
  <p>
    Sometimes, the use of a gyroscope sensor can result in incorrect setpoint calculation. There is evidence for this in that after the robot has turned, it may not be turned precisely 90 degrees, maybe less or more. So, a correction formula is applied that corrects the reading from the gyro and calculates the correct set point.
  </p>
  <p><strong>Angle Calculation Formula:</strong> Angle = atan<sup>-1</sup>((DS1 - DS2) / DS1S2)</p>
<br>
  <figure>
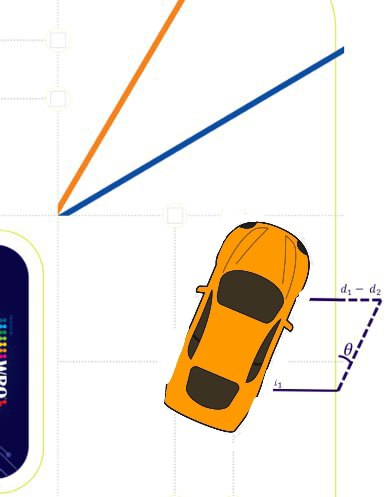
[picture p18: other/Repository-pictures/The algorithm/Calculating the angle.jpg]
Diagram showing angle calculation
    
    <br> 
    <figcaption>Figure 33: Angle Calculation</figcaption>
  </figure>
  <br>
  <br> 
  <p>
    Final output can be calculated using the formula below:
  </p>
  <p><strong>Servo Angle Formula:</strong> ServoAngle = Angle + PIDOutput</p>
  <dl>
    <dt>PIDOutput</dt>
    <dd>is the calculated servo angle using PD only.</dd>
    <dt>SetPoint</dt>
    <dd>is the reference angle (in which the robot is parallel to the wall).</dd>
    <dt>Error</dt>
    <dd>is the difference between the current reading and SetPoint in time <em>t</em>.</dd>
    <dt>Kp</dt>
    <dd>is the proportional gain.</dd>
      <dt><strong>Kd</strong></dt>
  <dd>is the derivative gain.</dd>
  <dt><strong>IntervalLength</strong></dt>
  <dd>is the time period to take one measurement.</dd>
  <dt><strong>DS1</strong></dt>
  <dd>is the front right/left sensor reading.</dd>
  <dt><strong>DS2</strong></dt>
  <dd>is the rear right/left sensor reading.</dd>
  <dt><strong>DS1S2</strong></dt>
  <dd>is the distance between the front right/left sensor and the rear right/left sensor.</dd>
  <dt><strong>Angle</strong></dt>
  <dd>is the angle between the robot and the wall.</dd>
  <dt><strong>ServoAngle</strong></dt>
  <dd>is the final servo angle.</dd>
  </dl>

<section>
  <h3>2-Obstacle Challenge</h3>
  <p>
    There are a few issues with the current vehicle, which utilizes Raspberry Pi Camera Module 3. For this, we suggest upgrading to the Intel RealSense Depth Camera D435 since it will resolve all of these issues and improve reliability in general. The camera is used to provide accurate depth perception so it can measure how far away Pillars and other solid obstacles are. In addition, a wider field of view helps detect obstacles. Its integrated Inertial Measurement Unit (IMU) provides motion tracking better depth accuracy and more stable than ever. This is especially useful in dynamic environments where the vehicle needs to quickly respond.
  </p>
</section>
<section>
  <h3>3-Differential</h3>
  <p>
    In our current design, we utilized a LEGO differential; however, we observed some shortcomings, specifically its low durability and the high flexibility of the LEGO axles. To enhance the vehicle’s performance, we recommend using a metal differential with metal axles, which offers greater durability and reduced flexibility.
  </p>
</section>
<section>
  <h3>4-Micro-controller Upgrade</h3>
  <p>
    In our vehicle, we utilized an Arduino Mega 2560 to control the motors and process sensor outputs, and a Raspberry Pi 4 with a camera to capture images, detect pillars, and send signals to the Arduino for appropriate actions. However, we observed some limitations, particularly in the computational power and integration complexity of using two separate devices. To enhance the system’s performance and streamline the architecture, we recommend using an NVIDIA Jetson Nano. The Jetson Nano provides significantly more computational power, allowing for advanced algorithms, real-time data processing, and machine learning applications. Designed specifically for AI applications, it can handle deep learning and image processing tasks, which are essential for complex navigation and obstacle avoidance. This upgrade would consolidate the tasks currently managed by both the Raspberry Pi 4 and the Arduino into a single, more powerful unit.
  </p>
<h3>5- Sensor Upgrades</h3>

  <b>Distance Measurement</b>
  <p>
    The current setup using Ultrasonic Sensors (HC-SR04) presents several limitations. To address these issues and improve system reliability, we recommend upgrading to Time-of-Flight (ToF) Sensors (VL53L1X) or LiDAR (RPLIDAR A1). This upgrade will resolve the existing problems (e.g., delay in responding) and enhance overall performance. ToF sensors and LiDAR deliver more accurate distance measurements, which are crucial for detecting how far away the surrounding objects are. Furthermore, they offer a faster response time, essential for real-time wall and obstacles detection. Both sensors also provide better range and resolution, significantly boosting navigation capabilities.
  </p>
</section>
<section>
  <b>MPU Upgrade</b>
  <p>
    We identified some shortcomings in accuracy and stability with the MPU-6050 used in our current vehicle. To address these issues and improve the system’s performance, we suggest upgrading to the Bosch BNO055. The BNO055 features an advanced 9-axis sensor with integrated sensor fusion algorithms, offering enhanced accuracy in orientation and motion tracking. Additionally, it provides better stability by effectively managing drift and noise, ensuring consistent performance in dynamic environments.
  </p>
</section>
<section>
  <h3>6-Power Management System (PMS)</h3>
  <p>
    Our current design employs basic power distribution using a Li-Poly battery and DC-DC converters; however, there are opportunities to improve battery management and power stability. To address these issues, we suggest upgrading to a Battery Management System (BMS). A BMS monitors individual cell voltages, temperatures, and overall battery health, which helps extend battery life and ensures safe operation. Additionally, it provides efficient power distribution to all components, maintaining stable voltage levels and preventing power fluctuations.
  </p>
</section>
<h2>Conclusion</h2>
<p>In conclusion,the autonomous vehicle we made is designed to compete in the WRO 2024 Future Engineers Category. This car embodies a blend of theoretical and practical principles from mechanical and mathematical engineering, alongside intricate programming challenges and advanced computer vision techniques. We aim to contribute to the advancement of autonomous vehicles, recognizing their immense potential to transform global mobility and connectivity.
  and also to provid a rich informational resource that encompasses all the necessary knowledge from mechanical components to the details of software and computing needed for operation, this is intended for those who lack a source to aid them in similar endeavors.</p>
  <h2>References</h2>
[1] R. N. Jazar, Advanced Vehicle Dynamics. Springer, 2019, ISBN: 978-3-030-13062-6. DOI:10.1007/978-3-030-13062-6. : https://link.springer.com/book/10.1007/978-3-030-13062-6.<br>
[2] S. International, “Motortoy car sample lesson plan,” SAE Learn Education, 2016. : https://www.sae.org/binaries/content/assets/cm/content/learn/education/motortoycar-samplelessonplan.pdf.<br>
[3] W. H. Crouse and D. L. Anglin, Automotive Mechanics. McGraw-Hill, 2014. : http://opac-library.adamasuniversity.ac.in/cgi-bin/koha/opac-detail.plbiblionumber=14573.<br>
[4] L. Group. (2023). “Sustainability - product safety - materials,” : https://www.lego.com/ms-my/sustainability/product-safety/materials#:~:text=ABS,as%20LEGO%20DUPLO%C2%AE%20bricks.<br>
[5] Arduino, “Arduino mega 2560,” : https://store.arduino.cc/products/arduino-mega-2560-rev3.<br>
[6] H. Technology, “Bts7960 motor driver,” : https://uk.farnell.com/c/sensors-transducers/sensors/ultrasonic-sensors.<br>
[7] E. Wings, “Mpu 6050,” : https://www.electronicwings.com/sensors-modules/mpu6050-gyroscope-accelerometer-temperature-sensor-module.<br>
[8] F. UK, “Ultrasonic sensor,” : https://uk.farnell.com/c/sensors-transducers/sensors/ultrasonic-sensors.<br>
[9] S. A. Saleh, D. Jewett, and S. A. R. Panetta, “The analysis, modeling, and capabilities of grounding system designs,” IEEE Transactions on Industry Applications, vol. 58, no. 5, pp. 5908–5920, 2022.<br>
[10] Besomi, “XL4005 DC-DC adjustable step-down module power supply converter,” : https://besomi.com/product/xl4005-dc-dc-adjustable-step-down-module-power-supply-converter/.<br>
[11] Moviltronics, “Servo MG996R,” : https://moviltronics.com/tienda/servo-mg996r/.<br>
[12] Techmaze, “Product 99187969,” : https://store.techmaze.ae/product/99187969.<br>
[13] Banggood, “ZOP Power 11.1V 2700mAh 3S 30C Lipo Battery XT60 Plug,” : https://www.banggood.com/ZOP-Power-11_1V-2700mAh-3S-30C-Lipo-Battery-XT60-Plug-p-1116169.html.<br>
[14] Modern Physics, “Ackermann Steering Geometry,” : https://modern-physics.org/ackermann-steering-geometry/.<br>
[15] MIT, “Differential,” : https://web.mit.edu/2.972/www/reports/differential/differential.html.<br>
[16] color spaces : https://pythongeeks.org/color-spaces-and-conversion-in-opencv/.<br>
[17] object tracking : https://docs.opencv.org/3.4/df/d9d/tutorial_py_colorspaces.html.<br>
[18] Raspberry pi 4 product brief: https://datasheets.raspberrypi.com/rpi4/raspberry-pi-4-product-brief.pd.<br>
[19] Shutter speed : https://github.com/raspberrypi/picamera2.<br>
[20] Raspberry camera module 3: https://www.raspberrypi.com/documentation/accessories/camera.html.<br>
[21] JSumo 1000rpm: https://www.jsumo.com/jsumo-titan-dc-gearhead-motor-12v-1000-rpm-hp.<br>
[22] contour detection: https://ieeexplore.ieee.org/abstract/document/5459410.<br>
[23] contour detection: https://www2.eecs.berkeley.edu/Pubs/TechRpts/2010/EECS-2010-17.pdf.<br>
[24] contours in OpenCV: https://docs.opencv.org/4.x/d3/d05/tutorial_py_table_of_contents_contours.html.<br>
[25] Arduino mega shield: https://www.google.com/url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.<br>
[26] Wheels: https://nl.aliexpress.com/item/4001168072686.html.<br>
[27] IAEME Publication, Differential, https://iaeme.com/MasterAdmin/Journal_uploads/IJMET/VOLUME_8_ISSUE_5/IJMET_08_05_019.pdf.<br>
[28] Roymech, Useful Tables: Drive Differentials, https://roymech.org/Useful_Tables/Drive/Differentials.html.<br>
[29] SpeedingParts, Ackermann Steering, https://www.speedingparts.eu/i/guides-and-information/chassis/ackermann-steering.html.<br>
[30] James Cole, Ackerman Steering Mechanism Design Project, https://sites.nd.edu/james-cole/ackerman-steering-mechanism-design-project/.<br>
[31] IJSER Publication, Mathematical Model to Design Rack And Pinion Ackerman Steering Geometry, https://www.ijser.org/researchpaper/Mathematical-Model-to-Design-Rack-And-Pinion-Ackerman-Steering-Geomtery.pdf.<br>
[32] Semantic Scholar, Ackerman Steering Geometry, https://pdfs.semanticscholar.org/8d78/832b9cfd0361379699bc34380213244d1bef.pdf.<br>

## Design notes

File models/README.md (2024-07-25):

<b>This directory contains the <code>STL folder</code>, which includes the 3D designs we have printed and used in the vehicle. It also contains another folder named <code>solid</code>, which offers all designs in an editable format, provided for the public to benefit from.</b>

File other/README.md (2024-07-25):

<b>This directory includes:</b>
<br>
<br>
<code>Flow_Charts:</code> It includes flowcharts that provide a simplified and clear explanation of the algorithm used in the competition.<br>
<code>Repository-pictures:</code> This folder includes all the images used in this repository.<br> 
<code>Software setup.md file:</code> It explains how to set up the software, install programs, and download the necessary libraries to facilitate learning and access to information.

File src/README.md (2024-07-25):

Control software
====

This directorycontain code for control software which is used by the vehicle to participate in the competition and which was developed by the participants.
<p><b>This directory includes:</b></p>
<code>Test and calibration:</code> This directory includes all the codes used for testing both the sensors and motors, in addition to the color calibration code used for adjusting the camera.<br>
<code>Arduino code:</code>includes Arduino C code used for executing the algorithm, controlling motor movement, and reading sensors. Additionally, it contains Python code for image processing and object detection.

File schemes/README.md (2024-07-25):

Electromechanical diagrams
====

<p>This directory includes several schematic diagrams of the electromechanical components illustrating all the elements (electronic components and motors) used in the vehicle and how they connect to each other.</p>
<p>Contents:</p>
<code>Circuit:</code> which includes images featuring a representation of the circuit, detailing how to connect the pieces and the components that comprise the circuit, along with a schematic of the circuit and its corresponding fzz files.
  <br>
<code>Schematic diagrams:</code> includes schematics for numerous electronic components used in the vehicle.

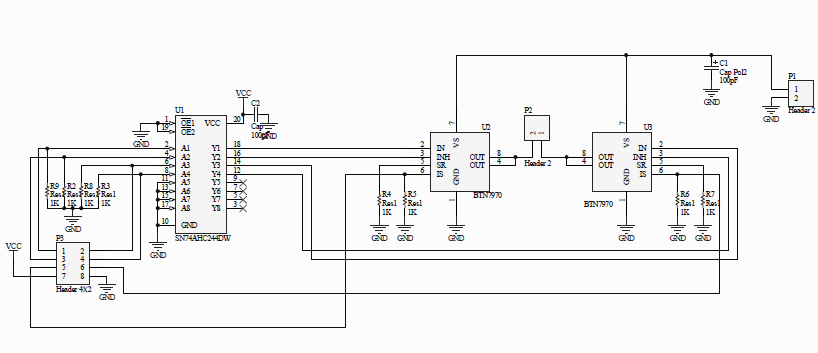
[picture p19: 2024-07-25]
schemes/Schematic diagrams/BTS7960.png

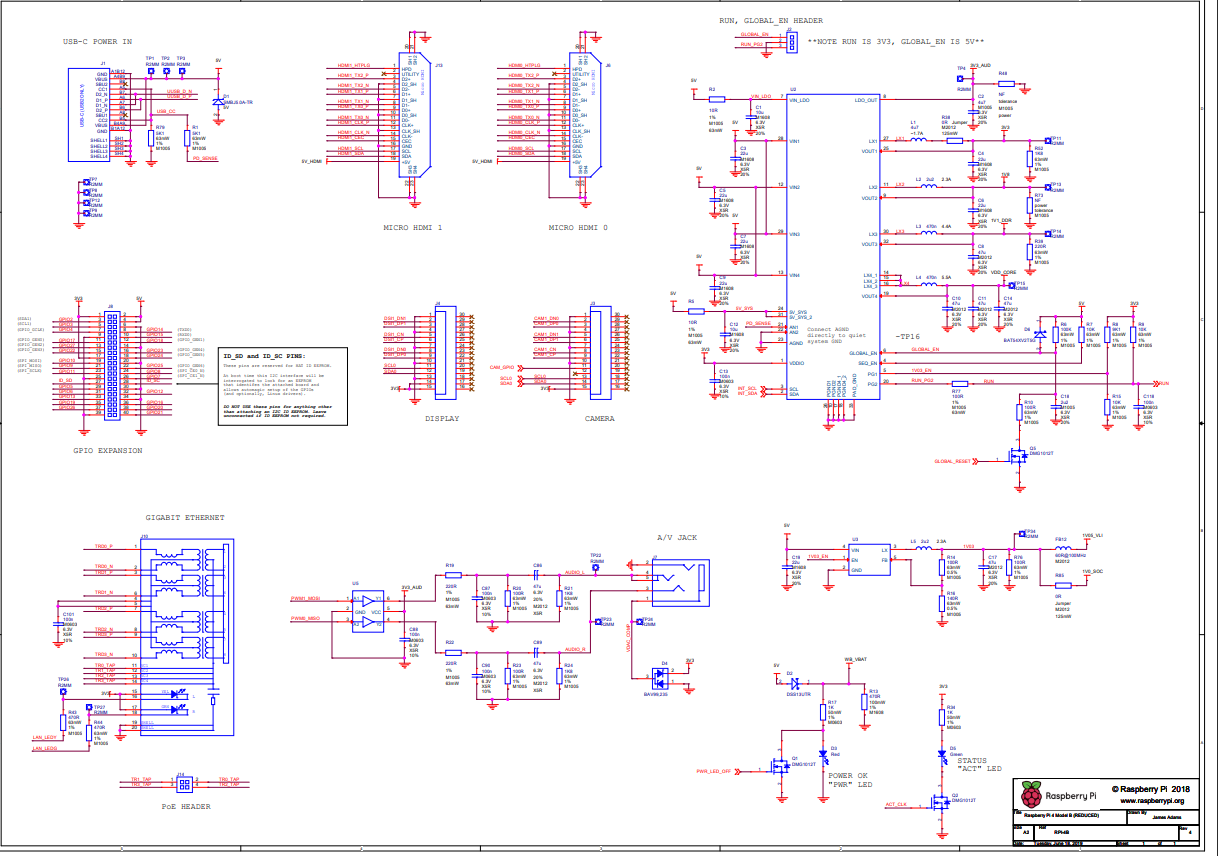
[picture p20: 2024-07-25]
schemes/Schematic diagrams/Raspberry_pi 4 model B.png

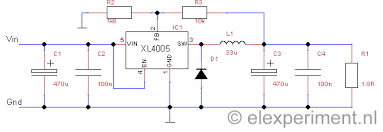
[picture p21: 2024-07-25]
schemes/Schematic diagrams/XL4005 DC DC converter.png

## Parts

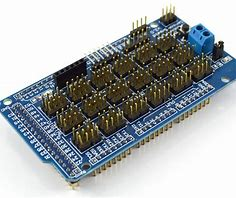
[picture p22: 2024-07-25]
other/Repository-pictures/Car's parts/Shield.png

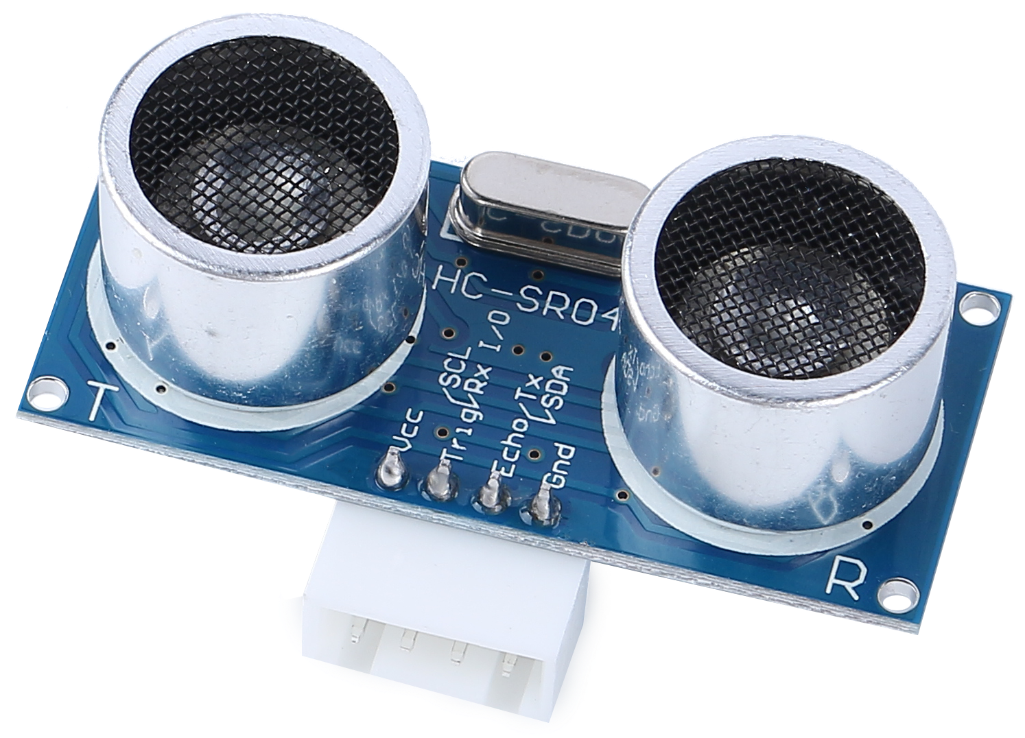
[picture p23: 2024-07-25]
other/Repository-pictures/Car's parts/UltraSonic.png

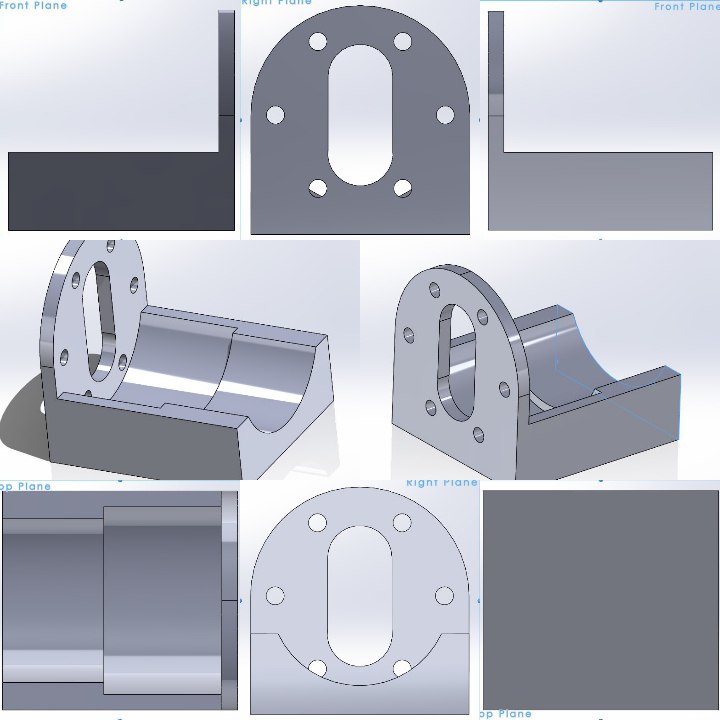
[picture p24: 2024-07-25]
other/Repository-pictures/Car's parts/motor_holder.jpg

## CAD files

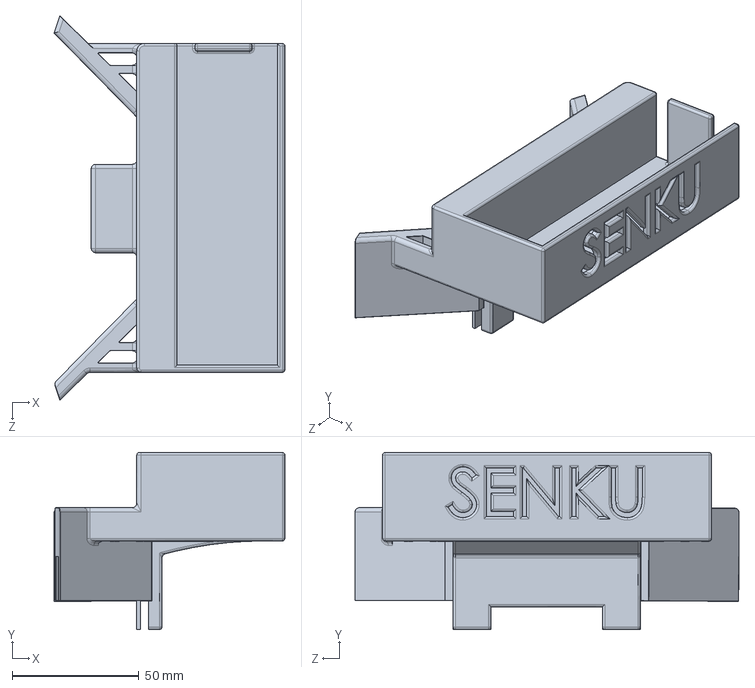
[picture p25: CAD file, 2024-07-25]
models/solid/battery_holder.SLDPRT
91.2 x 70.0 x 151.8 mm

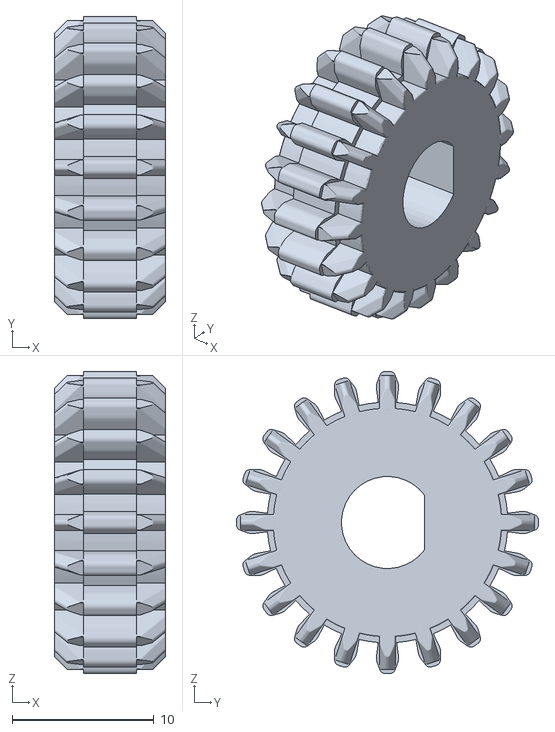
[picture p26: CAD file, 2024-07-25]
models/STL/Jsumo Tan Technic Gear 20 Tooth Double Bevel.STL
7.86 x 21.3 x 21.3

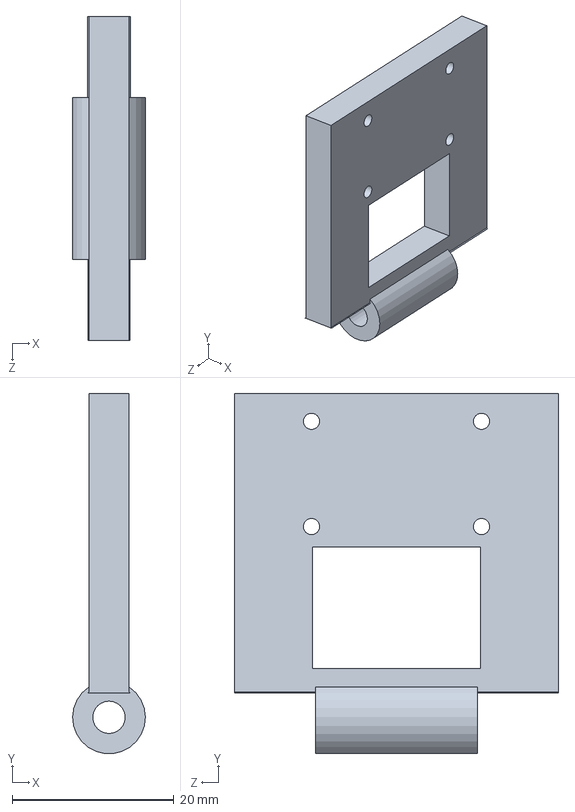
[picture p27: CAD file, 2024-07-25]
models/solid/camera_holder_Part2.SLDPRT
9.00 x 44.5 x 40.0 mm

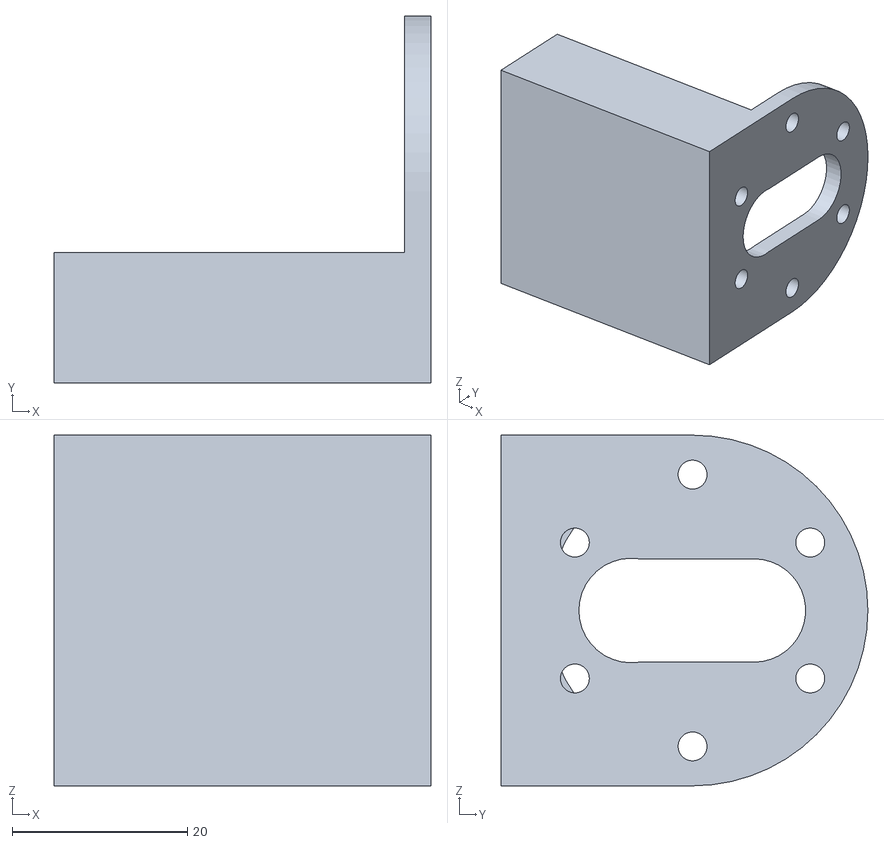
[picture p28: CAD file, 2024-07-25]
models/STL/JSumo_Motor_Holder 2.STL
43.0 x 41.8 x 40.0

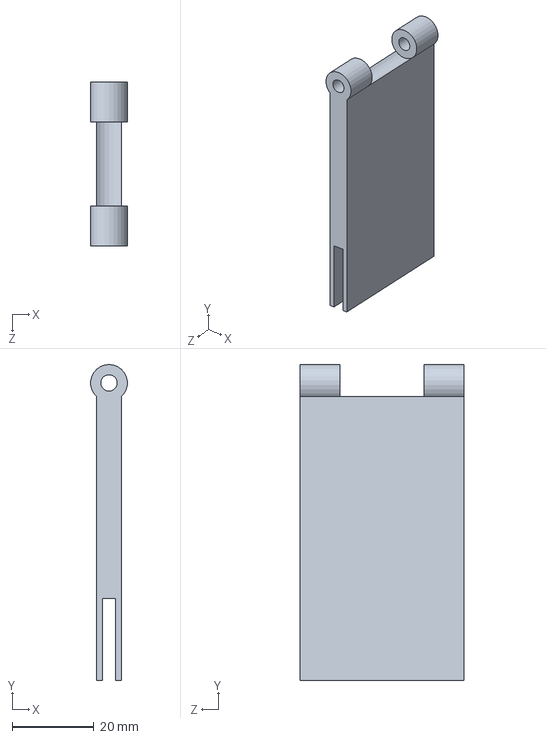
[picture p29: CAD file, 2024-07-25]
models/solid/camera_holder_Part1.SLDPRT
8.94 x 77.2 x 40.0 mm

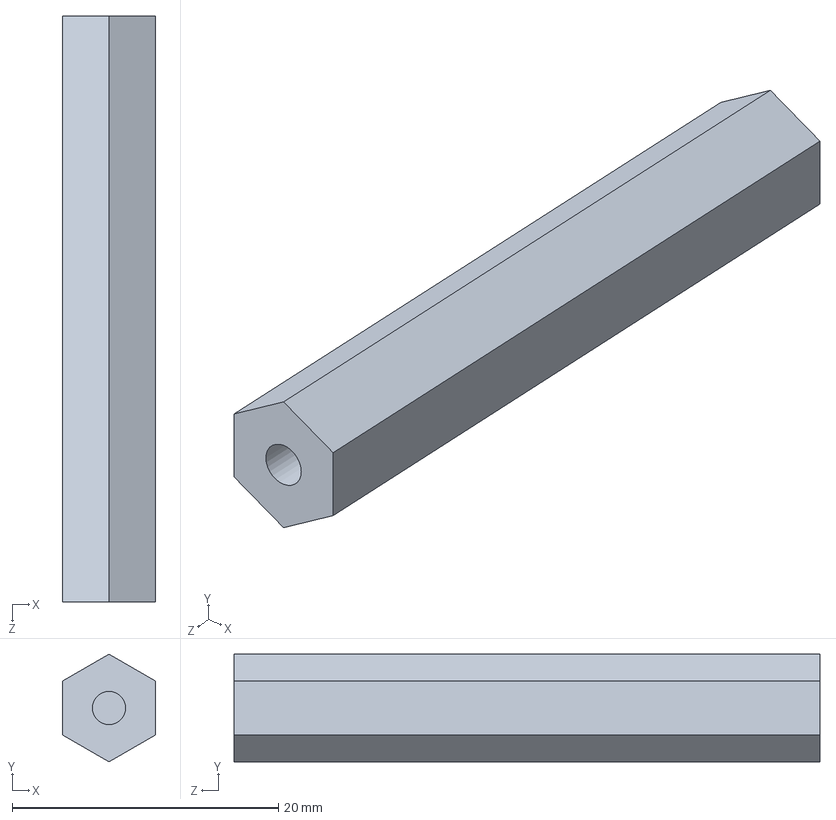
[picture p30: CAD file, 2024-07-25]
models/solid/Hexagonal Rod.SLDPRT
7.00 x 8.08 x 44.0 mm

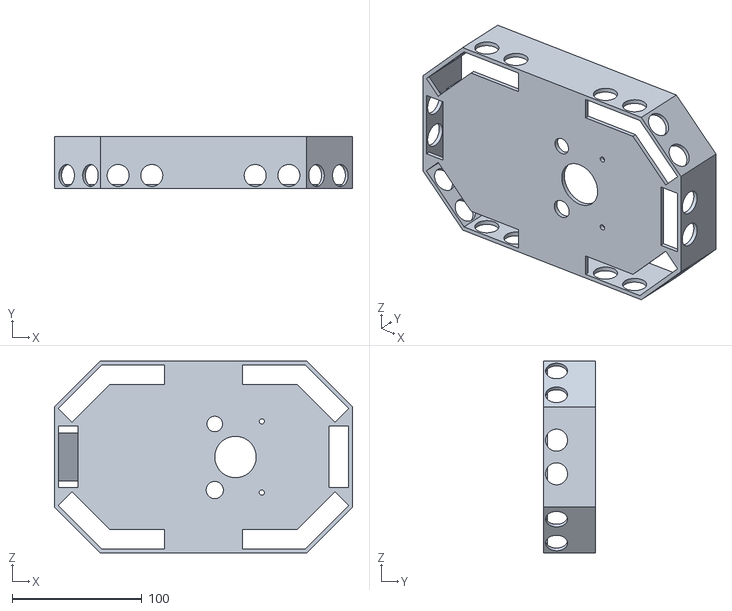
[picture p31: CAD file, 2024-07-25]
models/STL/Ultrasonic Sensor Holder Base.STL
230.0 x 40.0 x 148.0

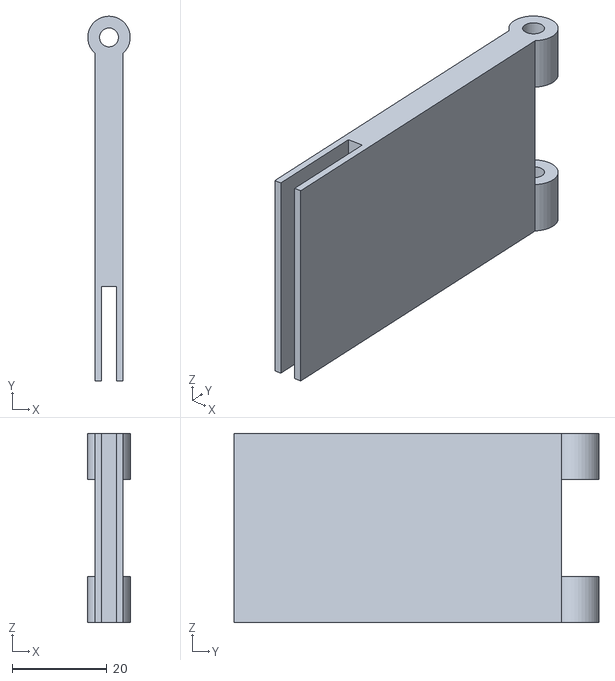
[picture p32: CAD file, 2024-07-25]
models/STL/camera_holder_Part1.STL
9.00 x 77.2 x 40.0

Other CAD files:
models/STL/battery_holder.STL
models/solid/Ultrasonic Sensor Holder Base.SLDPRT
models/STL/Hexagonal Rod.STL
models/solid/JSumo_Motor_Holder.SLDPRT
models/STL/camera_holder_Part2.STL

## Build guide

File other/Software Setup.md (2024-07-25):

<h1>Software Setup</h1> 
<h2>Contents</h2>

<dl>
  <dt>Software Setup</dt>
  <dd>-Setting Up and Configuring for Raspberry Pi.</dd>
  <dd>-Configuring Remote Access for Raspberry Pi.</dd>
  <dd>- Activating the Raspberry Pi Camera.</dd>
  <dd>- Downloading OpenCV library on Raspberry Pi.</dd>
  <dd>- Downloading the PySerial Library.</dd>
  <dd>- Downloading Picamera2 library.</dd>

<br>
<br>

<p>For effective applying to our self-driving car project, it's essential to configure software and install specific applications.We will be using Raspberry Pi for image processing, therefore, we will need to set up the <b>Raspberry Pi</b> device as well as enable and establish a remote connection for the Raspberry Pi.We will also need to activate the camera and download the applications that provide the necessary work environment for the accompanying codes. For this purpose, we will require the following applications:<p>

<h3>1- Setting Up and Configuring for Raspberry Pi</h3>

<p>Before you can use and control your Raspberry Pi, you must set up your Raspberry. To operate it, an operating system is required.you can install an operating system using <b>Imager</b> as follows:<p>

<ol type="I">
  <li>Download the latest version from <a href="raspberrypi.com/software">Raspberry PiOS</a>  and run the installer. Once you’ve installed Imager, launch the application by clicking the Raspberry Pi Imager icon </li>
  <br>
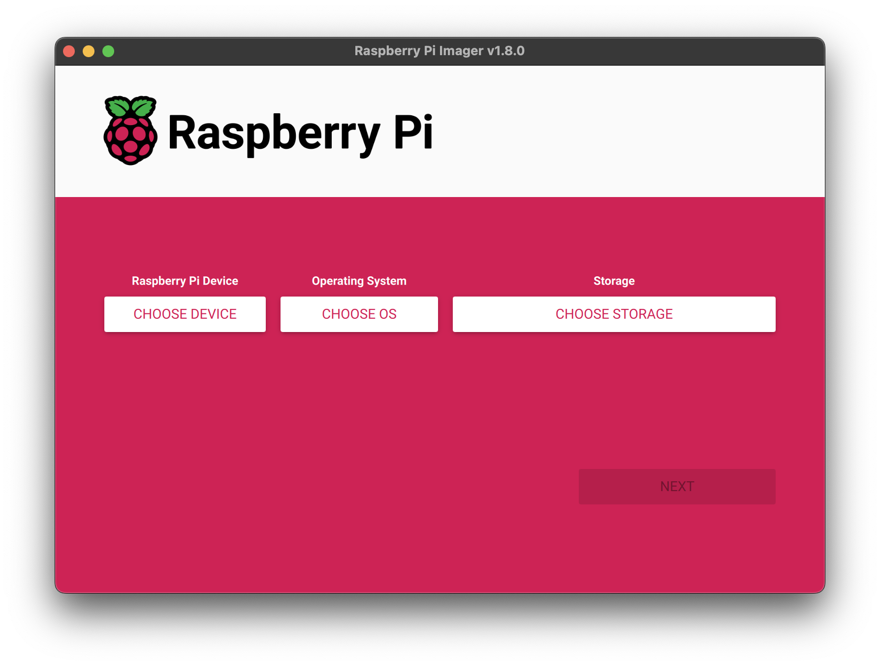
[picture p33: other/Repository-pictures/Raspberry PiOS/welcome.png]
The list of Raspberry Pi's models

  <br> 
    <figcaption>Figure 1: The list of Raspberry Pi's models</figcaption>
  </figure>
  <li>Select "Choose device" and pick your Raspberry Pi model from the dropdown list.(we are using Raspberry pi 4 in our Vehicle)</li>
  <br>
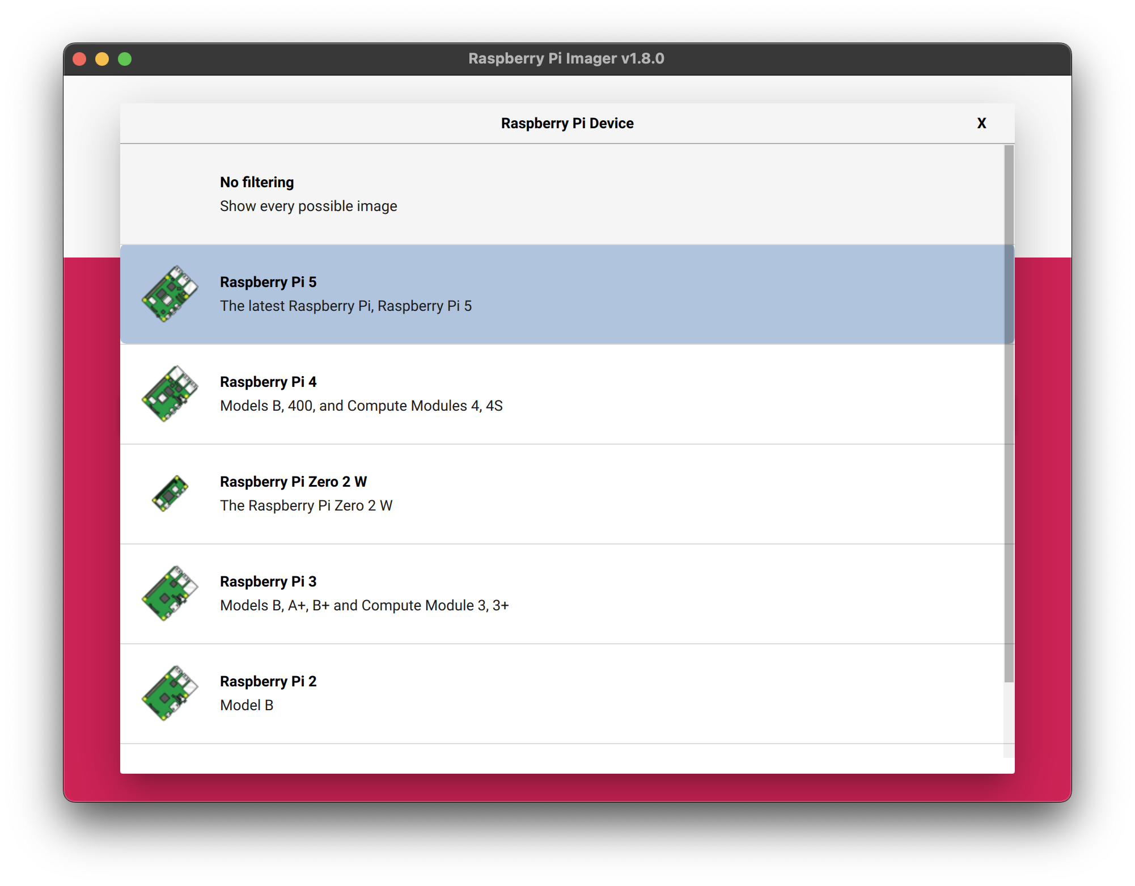
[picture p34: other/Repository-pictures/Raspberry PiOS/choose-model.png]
The list of Raspberry Pi's models
      
<br> 
    <figcaption>Figure 2:Picking your Raspberry Pi model</figcaption>
  </figure>
   <li>Next, click Choose OS and select an operating system to install</li>
   <br>
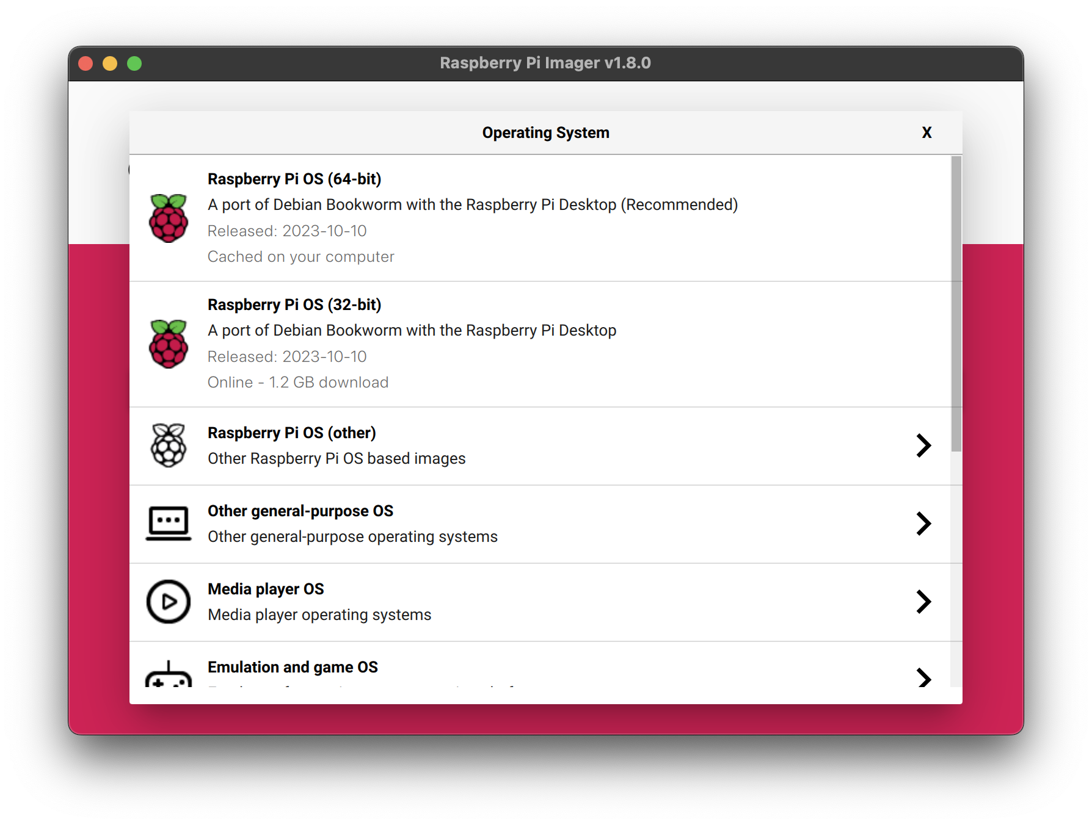
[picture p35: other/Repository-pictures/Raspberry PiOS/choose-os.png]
coosing the operating system


<br> 
    <figcaption>Figure 3: Selecting an operating system</figcaption>
  </figure>
   <li>Attach your chosen storage device to your computer. For instance, insert a microSD card via an external or integrated SD card reader. Subsequently, click on "Choose storage" and select the appropriate storage device.</li>
   <br>
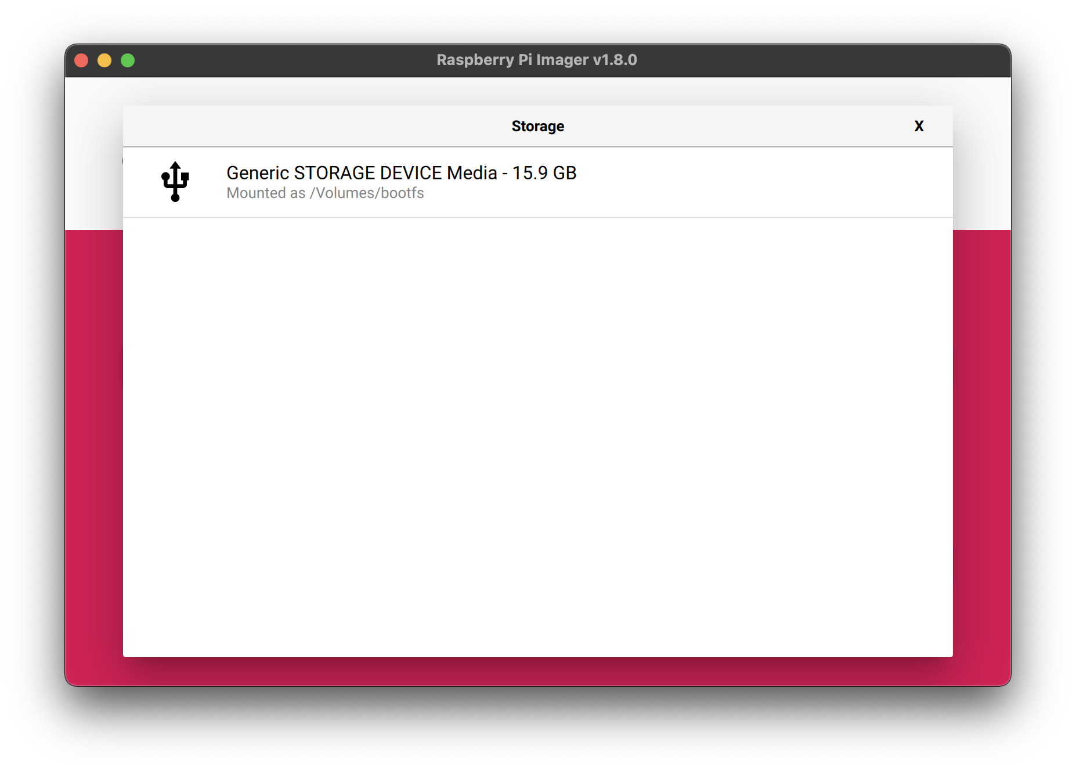
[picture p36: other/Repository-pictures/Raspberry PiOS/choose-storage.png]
Choosing the preferred storage
   
<br> 
    <figcaption>Figure 4:Choose storage</figcaption>
  </figure>
   <li>Imager will prompt you to apply operating system customizations. It is highly advisable to configure your Raspberry Pi using these OS customization settings. Select the "Edit Settings" button to access the OS customization options.</li>
   <br>

   <li>Upon accessing the OS customization menu, you may encounter a prompt to import Wi-Fi credentials from your current computer. Agreeing will automatically fill in the details from the network you are connected to, while declining allows for manual entry.<br>

The hostname setting allows your Raspberry Pi to be identified on the network via mDNS, making it accessible at <hostname>.local or <hostname>.lan.
You can set the administrative username and password under the username and password options.
The wireless LAN setting enables you to specify the SSID (name) and password for your network. For non-public SSIDs, activate the "Hidden SSID" option. 
<br>
Lastly, the locale settings allow customization of the time zone and keyboard layout for your Raspberry Pi.</li>
<br>
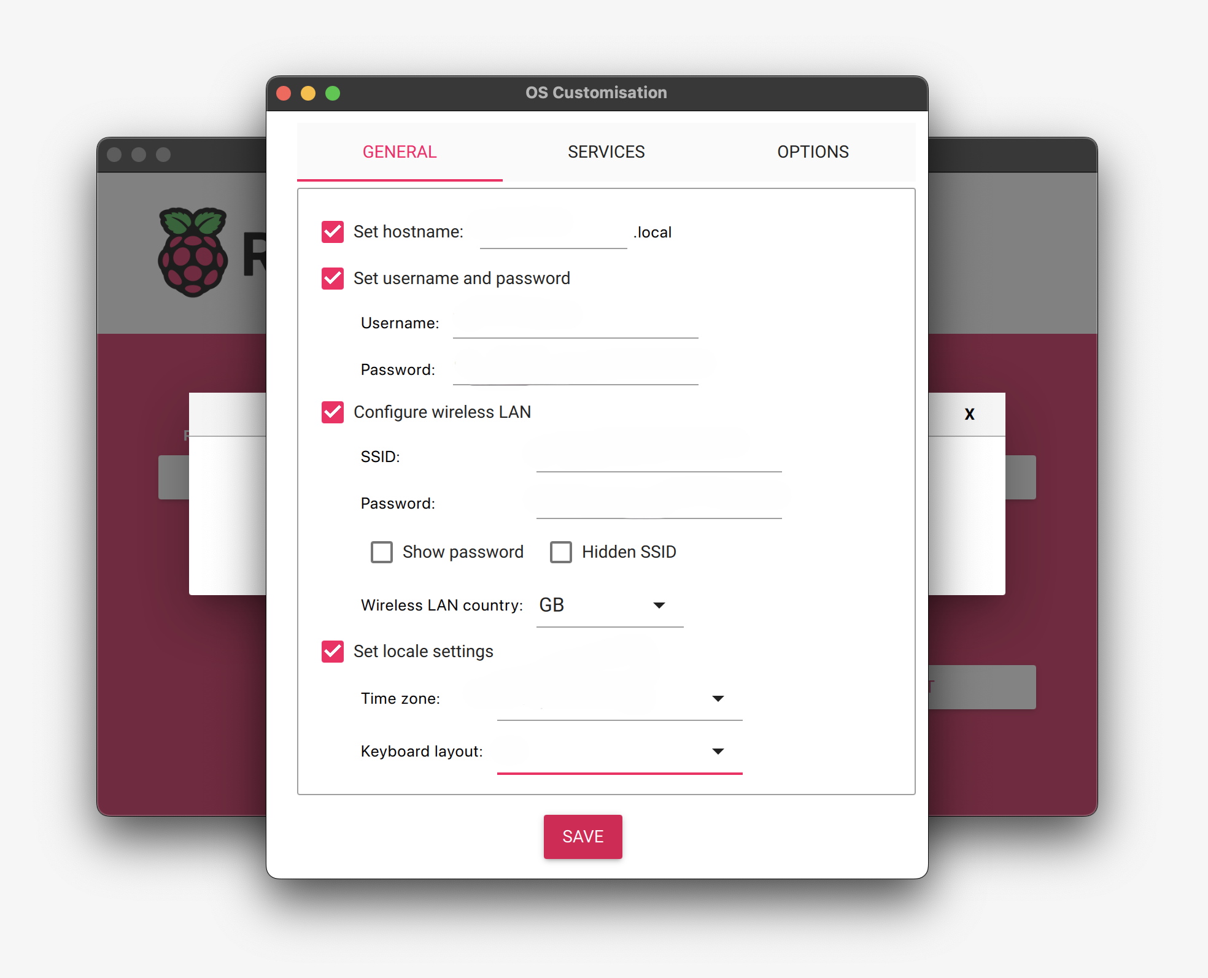
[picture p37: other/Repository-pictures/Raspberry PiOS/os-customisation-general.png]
editing setting

    <figcaption>Figure 5: OS customization options.</figcaption>
  </figure>

   <li>The Services tab contains options that facilitate remote access to your Raspberry Pi.

To manage your Raspberry Pi remotely via your network, ensure the Enable SSH box is checked. This is recommended for operating a headless Raspberry Pi.

Select the password authentication method for SSH access to your Raspberry Pi using the username and password set in the general tab of the OS customization.</li>
<br>
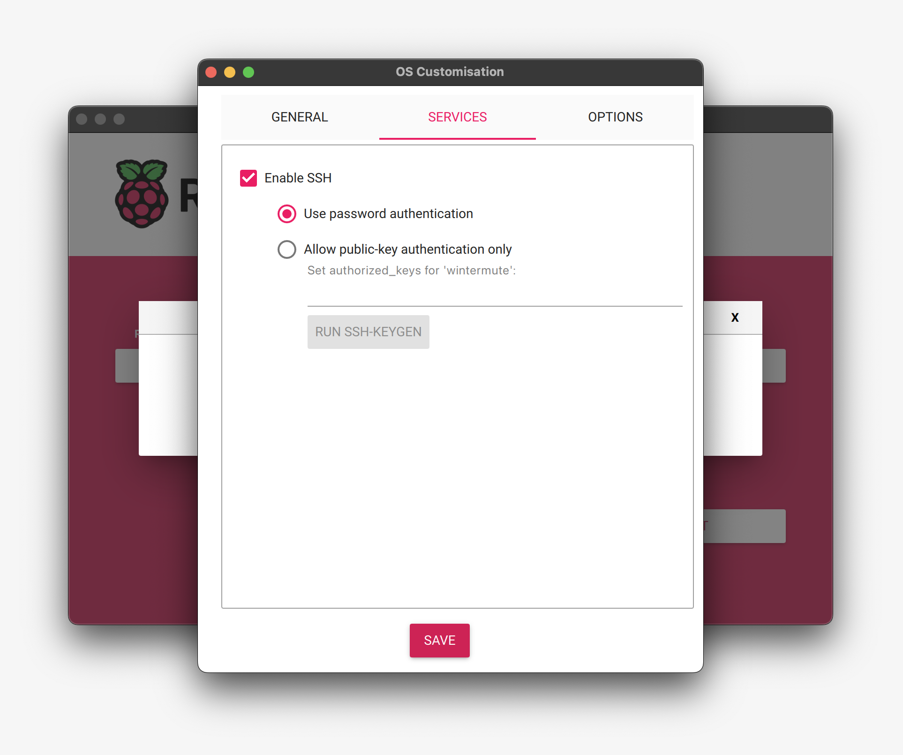
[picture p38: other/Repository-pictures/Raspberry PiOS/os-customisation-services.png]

 <figcaption>Figure 6: Selecting the password authentication method</figcaption>
  </figure>
   <li>After you have completed entering the OS customization settings, click "Save" to preserve your configurations.</li>
   <br>

   <li>Next, select "Yes" to confirm and apply the OS customization settings while writing the image to the storage device.</li>
   <br>

   <li>Lastly, confirm your action by clicking "Yes" in response to the "Are you sure you want to continue?" prompt, initiating the process of writing data to the storage device.</li>
 <br>

   <li>If an administrative prompt appears requesting permissions to read and write to your storage medium, grant the necessary permissions to Imager to continue.(you will have to wait, this takes a few minutes).</li>
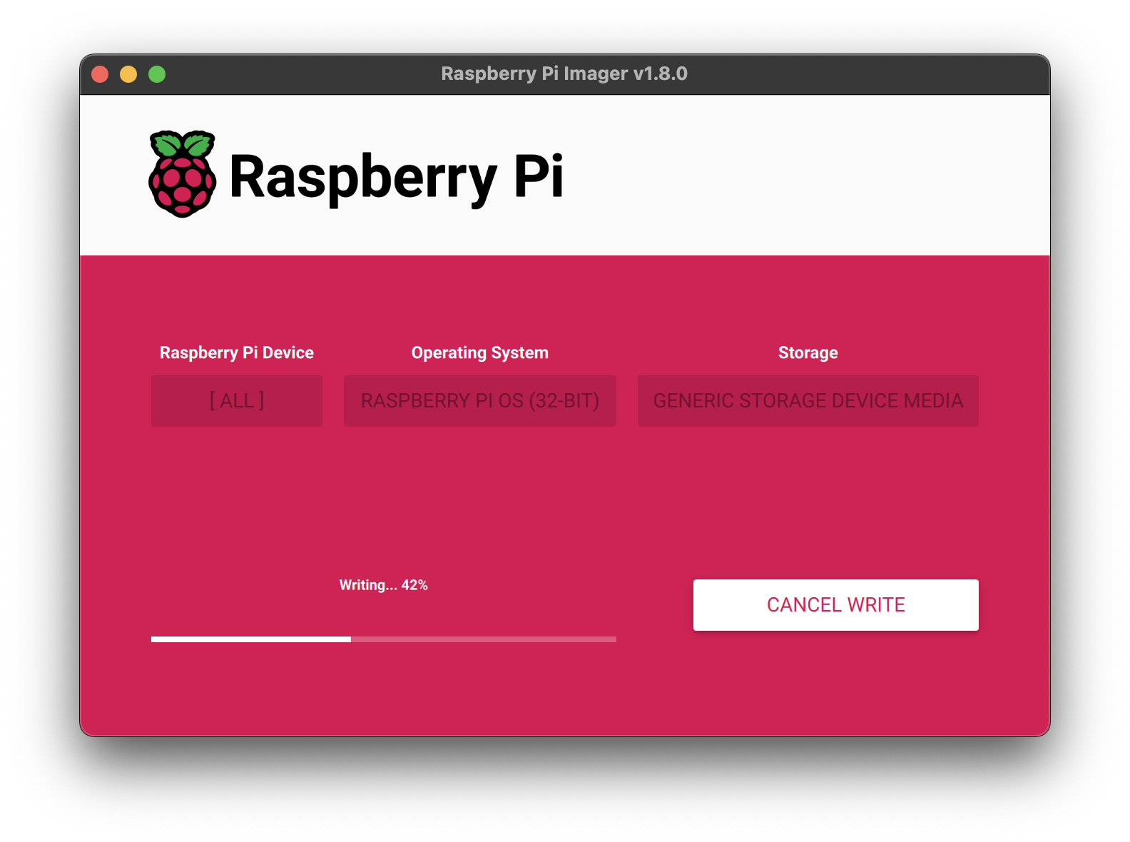
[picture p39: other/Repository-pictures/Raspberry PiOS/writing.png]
  
   <br> 
    <figcaption>Figure 7: Writing page</figcaption>
  </figure>

   <li>When you see the "Write Successful" popup, your image has been completely written and verified. You’re now ready to boot a Raspberry Pi from the storage device!</li>
 </ol>

 <h3>2- Configuring Remote Access for Raspberry Pi</h3>

<p>There are many ways to control your Raspberry Pi, but you will need to access a Raspberry Pi without connecting it to a monitor, keyboard, and mouse. we will need to manage it remotely to facilitate working on the car, and therefore we will need the following:</p>
<p>To manage your Raspberry Pi from a different device within your local network, consider utilizing <b>SSH</b>.<br> SSH (Secure Shell) is a protocol designed to establish a secure connection for remote access and management of systems such as the Raspberry Pi. By encrypting the data exchange between a local computer and a remote device, SSH facilitates the secure execution of commands, transfer of files, and administration of systems from a distance. This capability is particularly advantageous for managing Raspberry Pi configurations that lack direct physical access. Utilizing SSH allows for the effective control and setup of the Raspberry Pi from a separate computer via the network.<p>
<p>MobaXterm is the software that facilitates this communication, utilizing the SSH protocol.<p>

<ol type="I">
  <li> Download the software from the <a href="https://mobaxterm.mobatek.net/download-home-edition.html">provided link</a> and select the portable edition.</li>
  <br>

  <li>After downloading the software, extract it to a designated folder. The program will be ready for use once launched. Ensure that both the Raspberry Pi and your device are connected to the same network to view the interface properly.</li>
  <br>
  
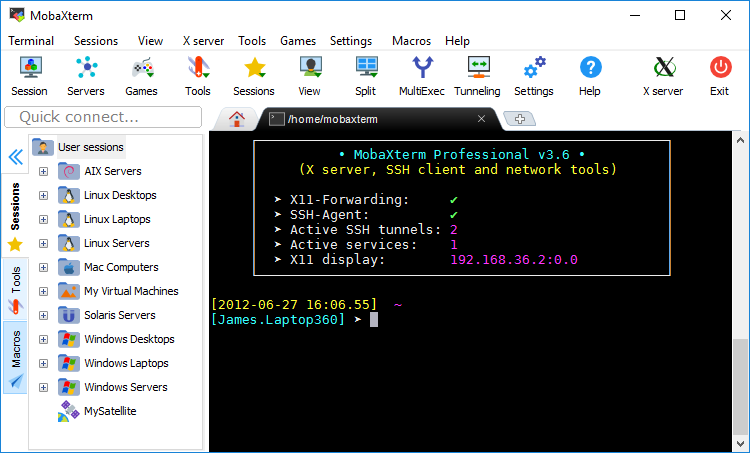
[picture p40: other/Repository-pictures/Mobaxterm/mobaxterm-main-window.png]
moba main window
  
   <br> 
    <figcaption>Figure 8:Moba main window</figcaption>
  </figure>
   <li>Select the "Session" tab. Afterward, you will need to modify the connection settings in the window that will appear next.</li>
   <br>
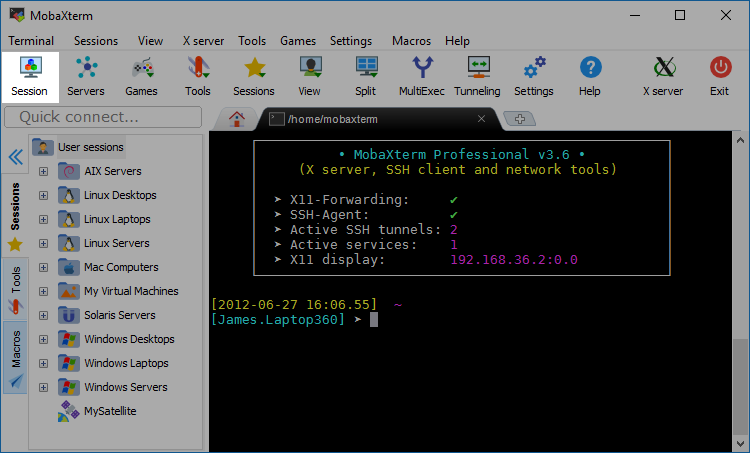
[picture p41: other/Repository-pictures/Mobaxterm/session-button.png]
starting a sission
   
    <br> 
    <figcaption>Figure 9: Starting a sission</figcaption>
  </figure>
   <li> Click on the SSH icon</li>
   <br>
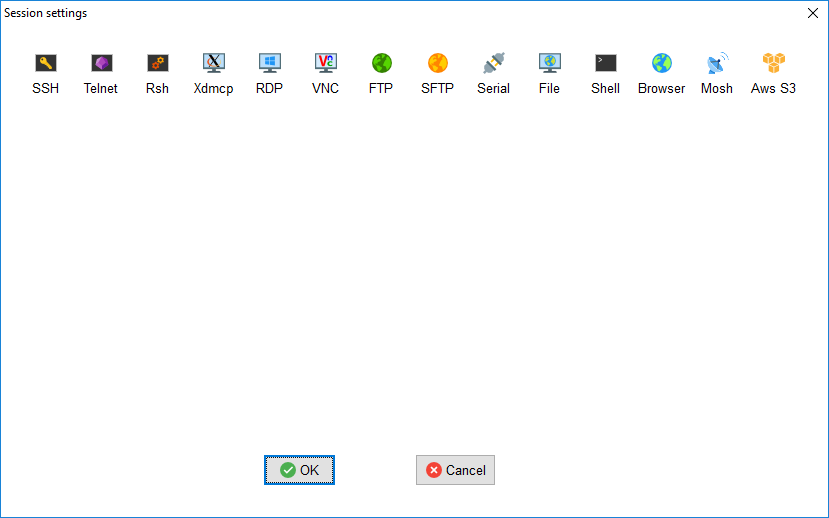
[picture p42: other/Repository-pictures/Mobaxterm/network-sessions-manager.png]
SSH connection
   
   <br> 
    <figcaption>Figure 10: SSH connection</figcaption>
  </figure>
   <li>We will need to add the IP address of the Raspberry Pi, or a device name can also be used which is here <b>raspberrypi.local</b>.  Then, we will utilize the LXDE desktop.</li>
   <br>
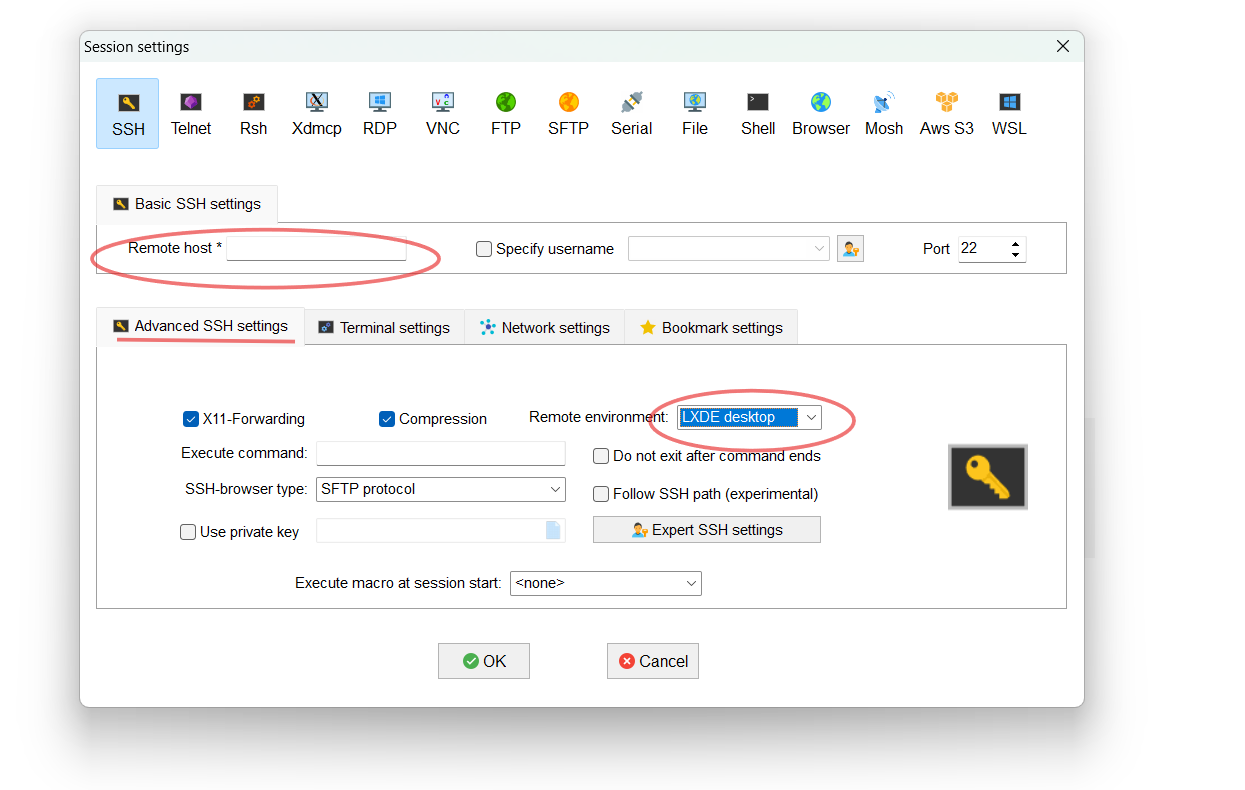
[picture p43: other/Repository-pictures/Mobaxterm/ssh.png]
   
   <br> 
    <figcaption>Figure 11: Connection settings</figcaption>
  </figure>
   <li>Now that the settings are configured, click 'OK'. You will then be prompted to enter the username and password that were established during the setup of the Raspberry Pi operating system.</li>
<br>
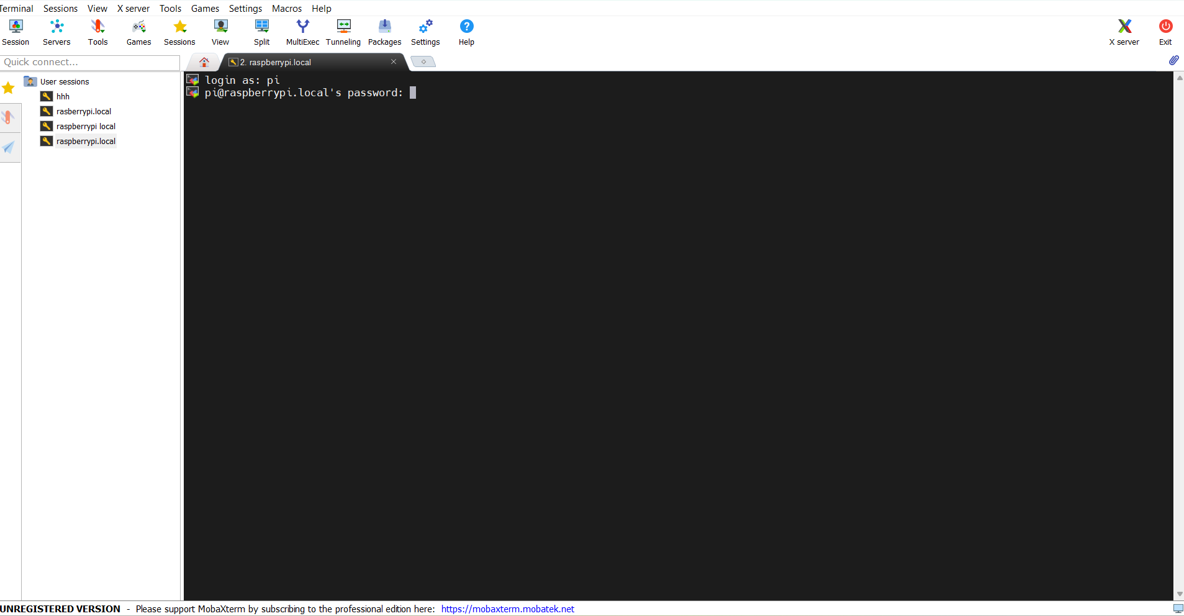
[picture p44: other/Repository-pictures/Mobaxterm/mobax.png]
intering the passowrd and the username

<br> 
    <figcaption>Figure 12: Intering the passowrd and the username</figcaption>
  </figure>
   <li>now a successful connection to the Raspberry Pi has been established, allowing for remote usage. An LXDE desktop window will open, and all subsequent activities will be conducted within this environment.</li>
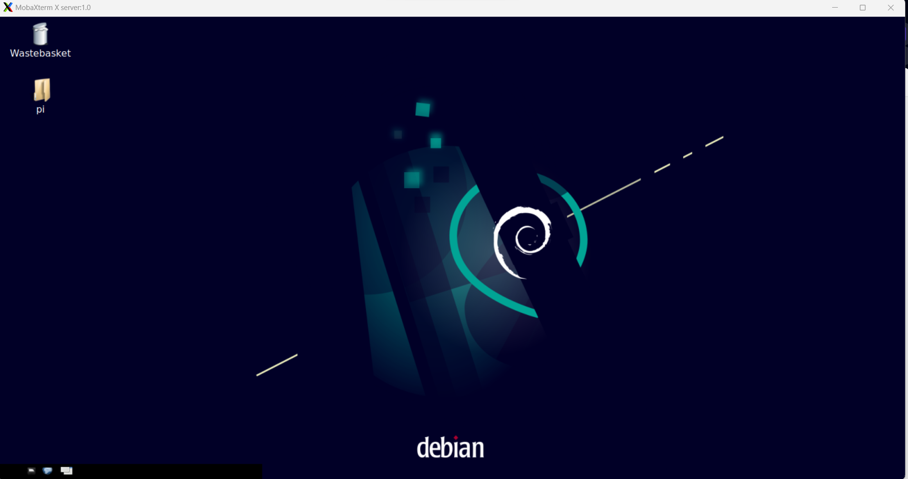
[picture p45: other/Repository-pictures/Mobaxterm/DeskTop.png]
A successful connection has been established.

<br> 
    <figcaption>Figure 13: A successful connection has been established.</figcaption>
  </figure>
 </ol>
<br>
<br>
<br>
 
 <p>If you want to shut down the Raspberry Pi, you must ensure the following steps are completed:</p>
 <ol type="I">
   <li> First, in the left corner, open the menu and select "System Tools," then click on "LXTerminal."</li>
   <br>
   <br>
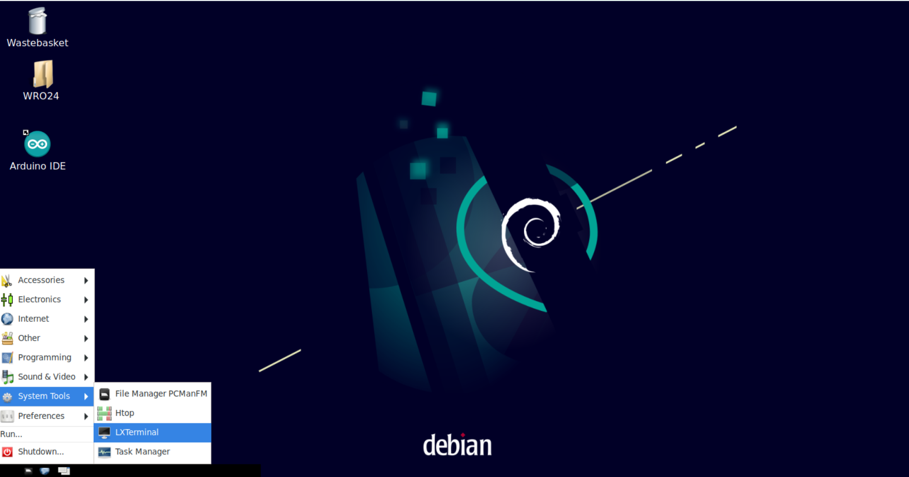
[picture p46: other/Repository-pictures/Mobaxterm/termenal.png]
   
   <br> 
    <figcaption>Figure 14: LXTerminal.</figcaption>
  </figure>
    <li>Using the arrow keys, press the up arrow, which will display the shutdown command (you can type it yourself or use the arrow keys to browse through available commands). Then, press the Enter key. </li>
   <br>
   
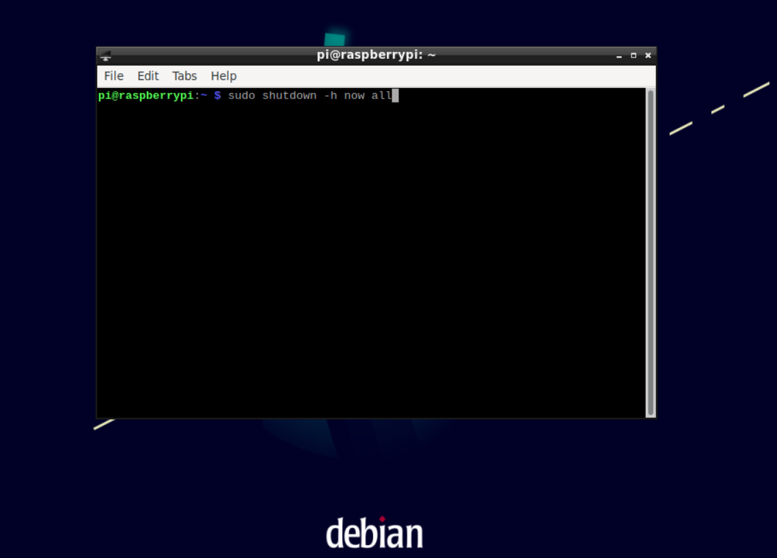
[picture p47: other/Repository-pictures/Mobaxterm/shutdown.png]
shutdown
   
   <br> 
    <figcaption>Figure 15: Shutdown command</figcaption>
  </figure>
   <li>Now the Raspberry Pi is shutting down. You should wait until it completely turns off before disconnecting the power supply. </li>
   <br>
   <br>
   </ol>

<h3>3- Activating the Raspberry Pi Camera</h3>
<p>The Raspberry Pi camera must be activated to start taking pictures, and this is done as follows:<p>
<ol type="I">
  <li>First you should write this command in the terminal:</li>
  <code>sudo raspi-config</code>
  <br>

  <li>You will see the Raspberry Pi settings window. Select the "Interfacing Options" by pressing the "Enter" key:</li>
  <br>
  <br>
  <br>
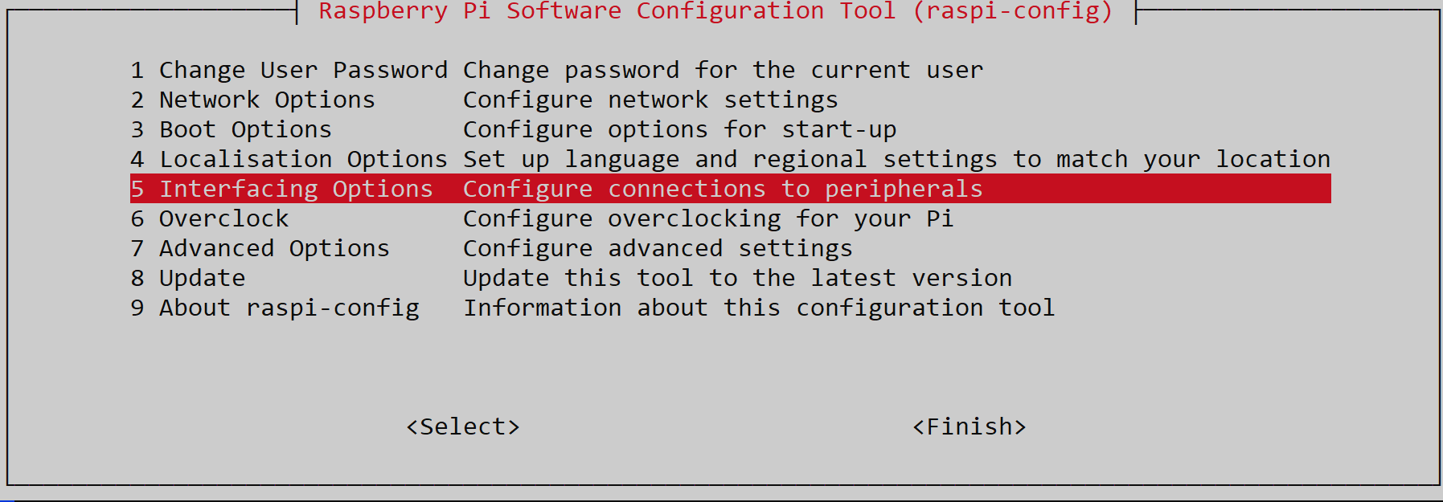
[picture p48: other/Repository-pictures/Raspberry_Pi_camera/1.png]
   
   <br> 
    <figcaption>Figure 16: Selecting the "Interfacing Options"</figcaption>
  </figure>
   <br>
   <br>
  <li> Now, select the camera option and press "Enter" to activate the camera.</li>
  <br>
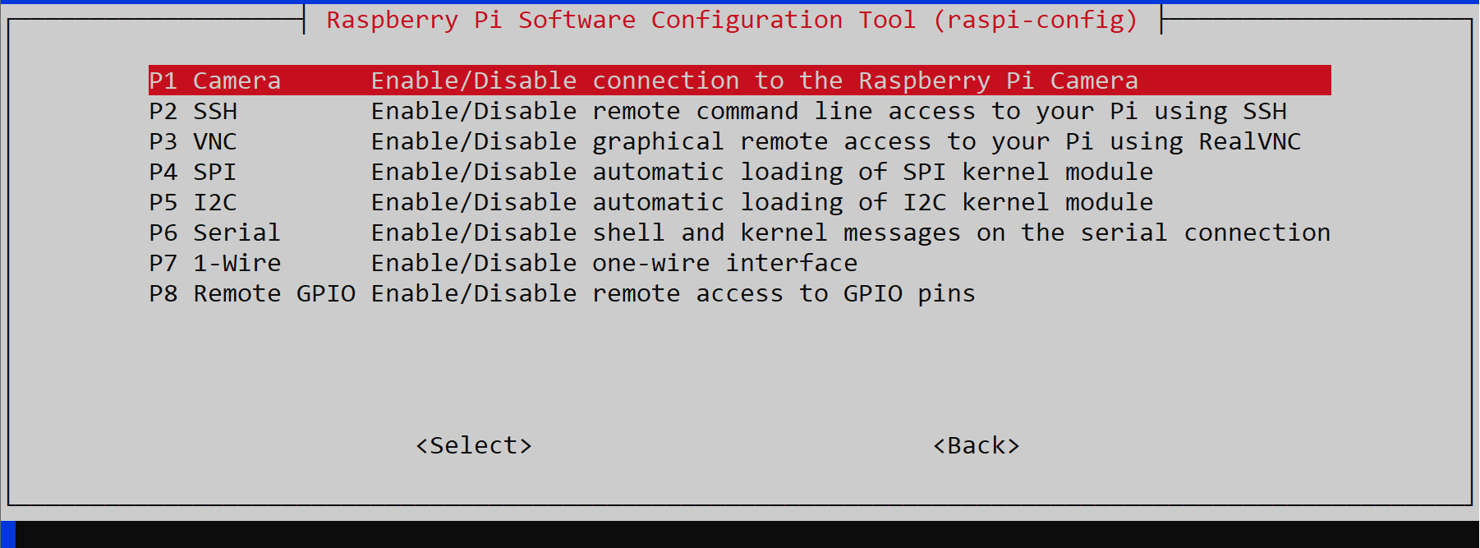
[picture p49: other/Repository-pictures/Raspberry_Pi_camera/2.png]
   
   <br> 
    <figcaption>Figure 17: Activating the camera.</figcaption>
  </figure>
   <br>
  <li>After completing the previous steps, press "ESC" to exit back to the original terminal, and then input the following command:</li>
  <code>sudo reboot</code>
  <br>
  </ol>

<h3>4- Setting Up the Arduino IDE on a Raspberry Pi</h3>
<p>We will download the Arduino IDE onto the Raspberry Pi to upload Arduino C code to the Arduino board via the serial connection between the Arduino and the Raspberry Pi. This will be done through the following steps:<p>

  <ol type="I">
  <li>Open the terminal by clicking on the terminal icon or by using the shortcut Ctrl+Alt+T.</li>
  <br>
  
  <li>Enter the following command:</li>
  <code>sudo apt install arduino</code>
  
  <br>
  <br>
  
  <li>Before utilizing the IDE, it is necessary to configure the permissions for the Arduino port on the Raspberry Pi. Connect the Arduino to the Raspberry Pi via a USB cable. Open the terminal on the Raspberry Pi and enter the following command to display the list of available ports on your Raspberry Pi:</li>
  <code>ls /dev/tty*</code>
  <br>
  <br>

  <li>
The Arduino port is likely to be identified as either<code>/dev/ttyACM0</code>  or <code>/dev/ttyUSB0</code>. By default, serial ports on the Raspberry Pi are inaccessible to standard users. To enable access to the Arduino port, utilize the `chmod` command to modify the permissions associated with the port. Execute the command below, substituting <code>*/dev/ttyACM0</code> with the actual port identifier you noted earlier:</li>

<br>
<code>ls /dev/tty*</code>
<br>
<br>

  <li>Once you've executed the chmod command, you will have the appropriate permissions to access the Arduino port, and you can begin using the Arduino with your Raspberry Pi.</li>
  <br>
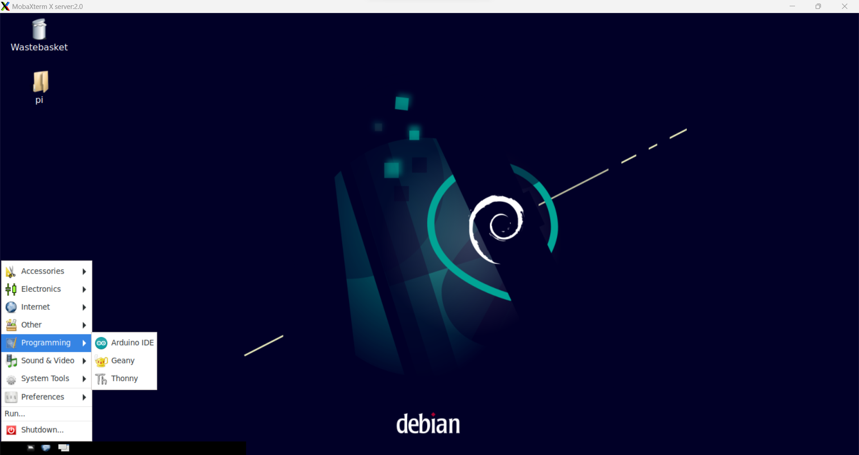
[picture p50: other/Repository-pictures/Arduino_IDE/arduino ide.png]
   
   <br> 
    <figcaption>Figure 18: Arduino IDE</figcaption>
  </figure>
  <br>
  </ol>
<h3>5- Downloading OpenCV library on Raspberry Pi.</h3>
<p>OpenCV, short for Open Source Computer Vision Library, is an open-source computer vision and machine learning software library allows you to perform various operations in the image like: Read the Image, Object detection, Image Enhacncement and others.
<ol type="I">
<li>Open the terminal, and type the following command:</li>
<code>sudo apt-get install python3-opencv</code>
<br>
<br>

<li>Once the installation to complete, open any code editor available under the programming tab. We will use Geany for our work (for Python codes).:</li>
<br>

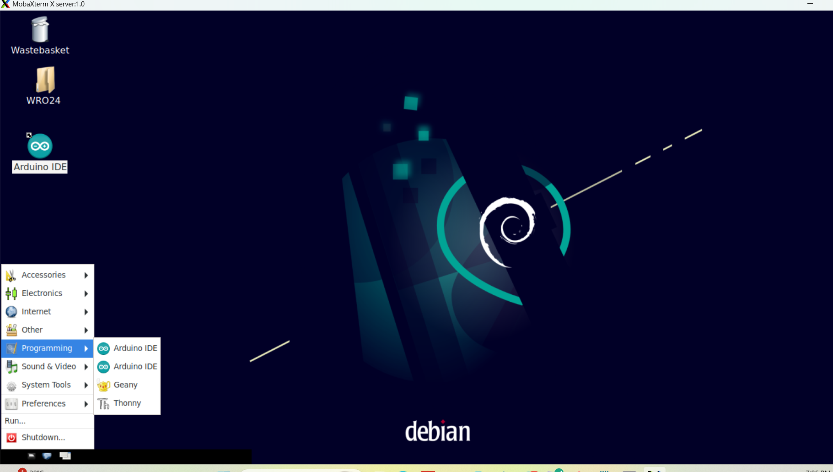
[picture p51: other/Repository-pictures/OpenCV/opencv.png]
 
 <br> 
    <figcaption>Figure 20: Programming tab.</figcaption>
  </figure>
<br>
<br>
<li>Import the library using the following command, and you are ready to use the library:
<code>import cv2</code>
<br>
<br>
</ol>

<h3> 6- Downloading the PySerial Library.</h3>

<p>PySerial is a Python library that provides access to the serial ports on a variety of operating systems. It is widely used for communication between microcontrollers and computers, enabling the exchange of data over serial communication protocols. We are going to use it  for establishing a successful connection between the Arduino and Raspberry Pi. It can be easily installed using the following command:<p>
<code>sudo apt-get install python-serial</code>

<h3>7- Downloading Picamera2 library</h3>
<p> Picamera2 is a Python library that gives convenient access to the camera system of the Raspberry Pi. It is designed for
 cameras connected with the flat ribbon cable directly to the connector on the Raspberry Pi itself, and not for other types
 of camera.<p>
 <p>Picamera2  provides a very direct and more accurate view of the Pi’s
 camera system, and makes it easy for Python applications to make use of them.<p>
<p>It can be conveniently installed with the following command:<p>
<code>sudo apt install python3-picamera2</code>

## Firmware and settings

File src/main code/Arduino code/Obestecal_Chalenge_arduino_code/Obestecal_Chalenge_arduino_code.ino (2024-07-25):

#include <ArduinoQueue.h>
#include <NewPing.h>
#include <Servo.h>
#include <math.h>
#include <MPU6050_light.h>


double First_reference = 0;                    // Initial reference angle
double gyro_ref = 0;                           // Gyroscope reference angle
double Pre_Time = 0, Cur_Time = 0;             // Time variables for calculations
double theta = 0, theta_mpu = 0, ref_mpu = 0;  // Angle variables
String data;                                   // Data received from sensors
bool Set_Servo = 1, Switch = 50;               // Servo settings and switch state
int start = 0;                                 // Start flag

int pos_R = 51, pos_R_back = 53, pos_L = 57, pos_L_Back = 49, turn_pos = 3, turn_pos2 = 3;  // Motor positions and turn settings

int Delay_Turn_Left = 1000, Delay_Turn_Right = 1150;                                             // Delays for turning
int delay_towide = 1200, delay_tonarrow = 1150;                                                  // Delays for path adjustments
int counter_angle_Right = 0, counter_angle_Left = 0, counter = 0;                                // Counters for angles and general purposes
int dis_narrow_F = 100;                                                                          // Distance for narrow path detection
double Position_L = pos_R - turn_pos, Position_R = pos_R + turn_pos2;                            // Calculated positions
double position_angle = 0;                                                                       // Angle for position calculation
double distance = 0, real_distance = 0, Real_dis_L = 0, Real_dis_R = 0, dis_L1 = 0, dis_L2 = 0;  // Distance variables for sensors
// Distance variables for each sensor
double dis_R1 = 0, dis_R2 = 0, dis_F = 0, dis_B = 0, dis_D2R = 0, dis_BL = 0, dis_D2L = 0, dis_BR = 0;

// Angle calculations and constants for PID control
double angle = 0, Angle = 0, Aangle = 0;
double conskpL = 0.32, conskpR = 0.95, kp = 1, kpl = 1, kpr = 1;  // PID constants
double conskp_NotstartR = 4, conskp_NotstartL = 2.1;              // PID constants when not starting
double Setpoint = 13, Setpoint_min = 7, Setpoint_max = 15;        // PID setpoints for various thresholds
double Setpoint_min_p = 21, Setpoint_max_p = 24;                  // PID setpoints for precise control
double highest_angle = 0.27;                                      // Highest angle threshold for control logic

// Miscellaneous variables
double pos_distance;                                                                                                                                                              // Positional distance variable for calculations
double jbes = 0;                                                                                                                                                                  // Placeholder variable (purpose to be defined)
double duration_F = 0, duration_L1 = 0, duration_L2 = 0, duration_R1 = 0, duration_R2 = 0, duration_B = 0, duration_BR = 0, duration_BL = 0, duration_D2R = 0, duration_D2L = 0;  // Duration of echo responses

// Speed settings for various maneuvers
int spd_now = 50;               // Current speed
int spd_turn_now = 50;          // Speed during turning
int spd_before_turn = 50;       // Speed before turning
int spd_before_turn_back = 50;  // Speed before turning back
int spd_Ob = 50;                // Speed during obstacle navigation
int spd_turn_Back_ob = 50;      // Speed during obstacle navigation turn back

// Angle range definitions for turning calculations
double max_ang = max(pos_R, pos_L) + 30;
double min_ang = min(pos_R, pos_L) - 30;
double min, max;  // Variables for storing minimum and maximum values

// PID controller variables for angle control
double currentTime_angle = 0, dtc = 0, lastTime_angle = 0;                  // Time variables for PID
double current_angle = 0, error_c = 0, output_c = 0, last_angle_error = 0;  // Current angle, error, and output for PID
double kpc = 1, kdc = 1;                                                    // PID coefficients
double reference = 0, reference_1 = 0;                                      // Reference angles for PID
int reference_counter = 5;                                                  // Counter for reference updates
double angle_mean = 0;                                                      // Average angle calculation

// Array to store conditions for cloros at each section
String Conditions[4] = { "", "", "", "" };
// Array to store conditions for parking lot posibilities
bool Pink[4] = { 0, 0, 0, 0 };
// Servo  initializations
Servo myservo;

//define for ultrasonic sensors pins

#define R_EN 35  // Right motor enable pin
#define L_EN 34  // Left motor enable pin
#define R_PWM 3  // Right motor PWM pin
#define L_PWM 2  // Left motor PWM pin


#define TRIGGER_PIN_F 38  // Front sensor trigger pin
#define ECHO_PIN_F 39     // Front sensor echo pin

#define D2R_trigger 50  // Diagonal right trigger pin
#define D2R_echo 51     // Diagonal right echo pin

#define D2L_trigger 41  // Diagonal left trigger pin
#define D2L_echo 40     // Diagonal left echo pin

#define B_trigger 48  // Back sensor trigger pin
#define B_echo 49     // Back sensor echo pin

#define BL_trigger 22  // Back-left sensor trigger pin
#define BL_echo 23     // Back-left sensor echo pin

#define BR_trigger 46  // Back-right sensor trigger pin
#define BR_echo 47     // Back-right sensor echo pin


#define TRIGGER_PIN_L1 44  // Left sensor 1 trigger pin
#define ECHO_PIN_L1 45     // Left sensor 1 echo pin

#define TRIGGER_PIN_L2 24  // Left sensor 2 trigger pin
#define ECHO_PIN_L2 25     // Left sensor 2 echo pin

#define TRIGGER_PIN_R1 32  // Right sensor 1 trigger pin
#define ECHO_PIN_R1 33     // Right sensor 1 echo pin

#define TRIGGER_PIN_R2 29  // Right sensor 2 trigger pin
#define ECHO_PIN_R2 28     // Right sensor 2 echo pin


#define MAX_DISTANCE 300  // Maximum distance for ultrasonic sensors


#define swi 30  // Switch pin

MPU6050 mpu(Wire);  // MPU6050 sensor for gyroscope data


// Sensor objects for ultrasonic measurements on all sides of the vehicle
NewPing sonar_L1(TRIGGER_PIN_L1, ECHO_PIN_L1, MAX_DISTANCE);
NewPing sonar_L2(TRIGGER_PIN_L2, ECHO_PIN_L2, MAX_DISTANCE);
NewPing sonar_R1(TRIGGER_PIN_R1, ECHO_PIN_R1, MAX_DISTANCE);
NewPing sonar_R2(TRIGGER_PIN_R2, ECHO_PIN_R2, MAX_DISTANCE);
NewPing sonar_F(TRIGGER_PIN_F, ECHO_PIN_F, MAX_DISTANCE);  // Front sensor
NewPing sonar_B(B_trigger, B_echo, MAX_DISTANCE);          // Back sensor
NewPing sonar_BL(BL_trigger, BL_echo, MAX_DISTANCE);       // Back-left sensor
NewPing sonar_BR(BR_trigger, BR_echo, MAX_DISTANCE);       // Back-right sensor
NewPing sonar_D2R(D2R_trigger, D2R_echo, MAX_DISTANCE);    // Diagonal-right sensor
NewPing sonar_D2L(D2L_trigger, D2L_echo, MAX_DISTANCE);    // Diagonal-left sensor

// Variables for holding the calculated distances
double f, fl, bl, fr, br, b;

// Function to get the distance from the front sensor
double get_distance_F() {
  duration_F = sonar_F.ping();    // Ping the sensor and get the echo response duration
  f = (duration_F / 2) * 0.0343;  // Calculate the distance based on sound speed
  return f;                       // Return the calculated distance
}

// Function to get the distance from the back sensor
double get_distance_B() {
  duration_B = sonar_B.ping();    // Ping the sensor and get the echo response duration
  b = (duration_B / 2) * 0.0343;  // Calculate the distance based on sound speed
  return b;                       // Return the calculated distance
}

// Function to get the distance from the back-left sensor
double get_distance_BL() {
  duration_BL = sonar_BL.ping();
  return (duration_BL / 2) * 0.0343;
}
  // Function to get the distance from the back-right sensor
  double get_distance_BR() {
    duration_BR = sonar_BR.ping();
    return (duration_BR / 2) * 0.0343;
  }

  // Function to get the distance from the left sensor 1
  double get_distance_L1() {
    duration_L1 = sonar_L1.ping();
    fl = (duration_L1 / 2) * 0.0343;
    return fl;
  }
    // Function to get the distance from the left sensor 2
    double get_distance_L2() {
      duration_L2 = sonar_L2.ping(101);
      bl = ((duration_L2 / 2) * 0.0343);
      return bl;
    }
    // Function to get the distance from the right sensor 1
    double get_distance_R1() {
      duration_R1 = sonar_R1.ping(101);
      fr = ((duration_R1 / 2) * 0.0343);

      return fr;
    }
    // Function to get the distance from the right sensor 2
    double get_distance_R2() {
      duration_R2 = sonar_R2.ping(101);
      br = ((duration_R2 / 2) * 0.0343);

      return br;
    }
    // Function to get the distance from the front right radical sensor

    double get_distance_D2R() {
      duration_D2R = sonar_D2R.ping();
      if (((duration_D2R / 2) * 0.0343) == 0)
        return 100;
      return ((duration_D2R / 2) * 0.0343);
    }
    // Function to get the distance from the front left radical sensor
    double get_distance_D2L() {
      duration_D2L = sonar_D2L.ping();
      if (((duration_D2L / 2) * 0.0343) == 0)
        return 100;
      return ((duration_D2L / 2) * 0.0343) - 3;
    }


    /*  NOTE: all functions mentioned in this code and start with "turn" are responsible for turning the robot in
            clockwise or counterclockwise dirction , the safety conditions are different in each one.(There are a few samples below:*/


    //a function to control servo motor movements with a specific constrains
    void myservo_write(double ang) {
      if (ang >= max_ang) ang = max_ang;
      if (ang <= min_ang) ang = min_ang;
      myservo.write(ang);
    }
    // a function to rotate robot in a specific angle in the clockwise dirction
    void turn_right_gyro(double v = 52.5, double ang = 75) {  // v is a setpoint for front sensor distance to make a turn in a safe place
      sensor();                                               // and ang is the angle of turn
      if (f < v) {
        Stop_Sumo(0);
        delay(50);
        while (f < v) {

          angle_Left_Back(bl, fl);  //@
          Back_Sumo(spd_before_turn_back);
          sensor();
        }
        Stop_Sumo(0);
        delay(200);


        Run_Sumo(spd_turn_now);
      }
      theta = ang - angle_cal(fl, bl) * 180 / acos(-1);
      mpu.update();


      theta_mpu = mpu.getAngleZ();
      ref_mpu = theta_mpu;
      theta = ref_mpu - theta;
      get_distance_F();
      delay(10);
      while (true)  //abs(theta_mpu - theta) >= 2 || f<150
      {
        if ((theta_mpu - theta) <= 0) break;  //&& f>150
        get_distance_F();
        mpu.update();
        theta_mpu = mpu.getAngleZ();
        delay(30);
        myservo_write(pos_R + 40);
      }
      myservo_write(pos_R);
      counter += 1;
      counter_angle_Left = 1;
    }
    // a function to rotate robot in a specific angle in the counterclockwise dirction

    void turn_left_GG_CCW_3(double ang = 75, double x = 60) {  // x is a setpoint for front sensor distance to make a turn in a safe place
      sensor();                                                //and ang is the angle of turn

      if ((f < x)) {
        Stop_Sumo(0);
        delay(50);
        while (f < x) {
          angle_Right(br, fr);  //@
          Back_Sumo(spd_before_turn_back);
          sensor();
        }
        Stop_Sumo(0);
        delay(50);

        Run_Sumo(spd_turn_now);
      }

      theta = ang;
      mpu.update();
      theta_mpu = mpu.getAngleZ();
      ref_mpu = theta_mpu;
      theta = ref_mpu + theta;
      get_distance_F();
      delay(10);
      dis_D2R = get_distance_D2R();
      delay(10);

      while (true) {
        if (((theta_mpu - theta) >= 0) || ((dis_D2R < 3) && (dis_D2R > 0))) break;  // && f>150
        mpu.update();
        theta_mpu = mpu.getAngleZ();

        myservo_write(pos_L - 50);
        get_distance_F();
        delay(5);
        dis_D2R = get_distance_D2R();
        delay(10);
      }
      myservo_write(pos_L);
      counter_angle_Right = 1;

      myservo_write(pos_L);
    }

    // a function to rotate robot in a specific angle in the counterclockwise dirction
    void turn_left_gyro(double ang = 75, double x = 60) {  // x is a setpoint for front sensor distance to make a turn in a safe place
      sensor();                                            //and ang is the angle of turn

      if (f < x) {
        Stop_Sumo(0);
        delay(50);
        while (f < x) {
          angle_Right(br, fr);  //@
          Back_Sumo(spd_before_turn_back);
          sensor();
        }
        Stop_Sumo(0);
        delay(50);

        Run_Sumo(spd_turn_now);
      }

      theta = ang - angle_cal(fr, br) * 180 / acos(-1);
      mpu.update();
      theta_mpu = mpu.getAngleZ();
      ref_mpu = theta_mpu;
      theta = ref_mpu + theta;
      get_distance_F();
      delay(10);
      while (true) {
        if ((theta_mpu - theta) >= 0) break;  // && f>150
        mpu.update();
        theta_mpu = mpu.getAngleZ();
        delay(30);
        myservo_write(pos_L - 50);
        get_distance_F();
      }
      myservo_write(pos_L);
      counter += 1;
      counter_angle_Right = 1;

      myservo_write(pos_L);
    }

    void turn_back_CW(double ang) {

      theta = ang;  //- angle_cal(fl, bl) * 180 / acos(-1);

      mpu.update();
      theta_mpu = mpu.getAngleZ();

      theta = mpu.getAngleZ() - theta;

      Back_Sumo(spd_turn_Back_ob);
      while (true) {
        if (((theta_mpu - theta) <= 0)) {
          break;
        }

        mpu.update();
        theta_mpu = mpu.getAngleZ();

        myservo_write(pos_R - 40);
        delay(30);

        Back_Sumo(spd_turn_Back_ob);
      }
      myservo_write(pos_R);
    }


    void turn_back_CCW(double ang) {

      theta = ang - angle_cal(fr, br) * 180 / acos(-1);

      mpu.update();
      theta_mpu = mpu.getAngleZ();

      theta = mpu.getAngleZ() + theta;

      Back_Sumo(spd_turn_Back_ob);
      while (true) {
        if (((theta_mpu - theta) >= 0)) {
          break;
        }

        mpu.update();
        theta_mpu = mpu.getAngleZ();

        myservo_write(pos_L + 50);
        delay(30);

        Back_Sumo(spd_turn_Back_ob);
      }
      myservo_write(pos_L);
    }


    void turn_back_parking(double ang) {
      sensor();
      theta = ang - angle_cal(fr, br) * 180 / acos(-1);

      mpu.update();
      theta_mpu = mpu.getAngleZ();

      theta = mpu.getAngleZ() + theta;
      dis_BL = get_distance_BL();

      Back_Sumo(spd_turn_Back_ob);
      while (true) {
        if (((theta_mpu - theta) >= 0) || (dis_BL < 3 && dis_BL > 0) || (b < 6.5 && b > 0)) {
          Stop_Sumo(0);

          break;
        }
        dis_BL = get_distance_BL();

        sensor();
        mpu.update();
        theta_mpu = mpu.getAngleZ();

        myservo_write(pos_L + 50);
        delay(30);

        Back_Sumo(spd_turn_Back_ob);
      }
      myservo_write(pos_L);
    }


    void turn_left_CW_parking(double ang) {
      sensor();
      dis_D2L = get_distance_D2L();

      theta = ang - angle_cal(fl, bl) * 180 / acos(-1);
      mpu.update();
      theta_mpu = mpu.getAngleZ();
      ref_mpu = theta_mpu;
      theta = ref_mpu + theta;
      Run_Sumo(spd_Ob);
      while (true) {
        sensor();
        dis_D2L = get_distance_D2L();

        if (((theta_mpu - theta) >= 0) || (dis_D2L < 2 && dis_BL > 0) || (f < 5 && f > 0)) {
          Stop_Sumo(0);

          break;
        }  // && f>150
        mpu.update();
        theta_mpu = mpu.getAngleZ();
        Serial.println(mpu.getAngleZ());
        delay(30);
        myservo_write(pos_R - 40);
      }
      myservo_write(pos_R);
    }
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
  void loop() {

    if (counter == 0) {  //in the start section the counter = 0, we have 3 cases R (Red pillar), G (Green pillar) and N (no pillars) and if GG, RR, GR and RG send that mean the second pillar is in another section
      spd_Ob = 40;
      mpu.update();
      First_reference = mpu.getAngleZ();
      if (Serial.available()) {
        data = Serial.readStringUntil('#');
      }
      if (data == "R" || data == "RR" || data == "RG") {

        R();
        Stop_Sumo(0);
        delay(200);
        if (counter_angle_Left == 1) {

          Serial.println("R");
        } else if (counter_angle_Right == 1) {

          Serial.println("L");
        }
      }

      else if (data == "G" || data == "GG" || data == "GR") {

        G();
        Stop_Sumo(0);
        delay(200);

        if (counter_angle_Left == 1) {

          Serial.println("R");
        } else if (counter_angle_Right == 1) {

          Serial.println("L");
        }
      } else if (data == "N") {
        Nan();
        Stop_Sumo(0);
        delay(200);
        if (counter_angle_Left == 1) {

          Serial.println("R");
        } else if (counter_angle_Right == 1) {

          Serial.println("L");
        }
      }
      counter++;

      spd_Ob = 45;
    }
    Serial.begin(115200);



    if (counter != 0, counter < 5) {  //in the first loop after the start section (counter != 0, counter < 5) the arduino tack output from the raspberry pi (RR,RG,GR,GG) and save it in array (condition), and check if there are pink parking lot
      if (Serial.available()) {
        data = Serial.readStringUntil('#');

        Conditions[counter % 4] = data[counter % 4];
      }

      if (counter_angle_Left == 1) {        // the dirction of movment ClockWise
        if (data == "R" || data == "RR") {  //red pillar or pillars was ditected
       
            RR();
      
          Stop_Sumo(0);
          Serial.println("R");

          delay(200);
        } else if (data == "G" || data == "GG") {  //Green pillar or pillars was ditected
          Run_Sumo(spd_Ob);
          if (Pink[counter % 4])  //if there are parking lot
          {
            GGP();
          } else {
            GG();
          }
          Stop_Sumo(0);
          Serial.println("R");

          delay(200);
        } else if (data == "RG") {  //red and Green pillars was ditected
          if (Pink[counter % 4])    //if there are parking lot
          {
            RGP();
          } else {
            RG();
          }
          Stop_Sumo(0);
          Serial.println("R");

          delay(200);
        } else if (data == "GR") {  //Green and red pillars was ditected
          if (Pink[counter % 4])    //if there are parking lot
          {
            GR(42);
          } else {
            GR();
          }
          Stop_Sumo(0);
          Serial.println("R");

          delay(200);
        }
      }

      ///////////////////////////////////////////////////////////////////////////////////
      else if (counter_angle_Right == 1) {  // the dirction of movment CounterClockWise
        if (data == "R" || data == "RR") {
          if (Pink[counter % 4]) {
            RRP_CCW();
          } else {
            RR_CCW();
          }
          Stop_Sumo(0);
          Serial.println("L");

          delay(200);
        } else if (data == "G" || data == "GG") {
          Run_Sumo(spd_Ob);
        
            GG_CCW();
          
          Stop_Sumo(0);
          Serial.println("L");

          delay(200);
        } else if (data == "RG") {
          if (Pink[counter % 4]) {
            RG_CCW(33);
          } else {
            RG_CCW();
          }
          Stop_Sumo(0);
          Serial.println("L");

          delay(200);
        } else if (data == "GR") {
          if (Pink[counter % 4]) {
            GRP_CCW();
          } else {
            GR_CCW();
          }
          Stop_Sumo(0);
          Serial.println("L");

          delay(200);
        }
      }
      counter++;
    }


    if (counter >= 5, counter <= 12) {  //after the first loop the arduino check the Conditions and Pink array, which it saved them before without taking any images
                                        //the navigation of the robot does not differe from the previous If-Condtion


      if (counter_angle_Left == 1) {
        if (Conditions[counter % 4] == "R" || Conditions[counter % 4] == "RR") {

            RR();
          

        } else if (Conditions[counter % 4] == "G" || Conditions[counter % 4] == "GG") {
          Run_Sumo(spd_Ob);
          if (Pink[counter % 4]) {
            GGP();
          } else {
            GG();
          }

        } else if (Conditions[counter % 4] == "RG") {
          RG();

        } else if (Conditions[counter % 4] == "GR") {
          if (Pink[counter % 4]) {
            GR(42);
          } else {
            GR();
          }
        }
      }

      ///////////////////////////////////////////////////////////////////////////////////
      else if (counter_angle_Right == 1) {
        if (Conditions[counter % 4] == "R" || Conditions[counter % 4] == "RR") {
          if (Pink[counter % 4]) {
            RRP_CCW();
          } else {
            RR_CCW();
          }

        } else if (Conditions[counter % 4] == "G" || Conditions[counter % 4] == "GG") {
          Run_Sumo(spd_Ob);

            GG_CCW();
  


        } else if (Conditions[counter % 4] == "RG") {
          if (Pink[counter % 4]) {
            RG_CCW(33);
          } else {
            RG_CCW();
          }



        } else if (Conditions[counter % 4] == "GR") {
          if (Pink[counter % 4]) {
            GRP_CCW();
          } else {
            GR_CCW();
          }
        }
      }
      counter++;
    }



    if (counter > 12) {  // after three laps
    for   (int i = 0; i < 3;i++)
    {
      if (Pink[counter % 4])  //if the vehicl is in the same section of the parking lot
      {
        parking();
        Stop_Sumo(0);
        delay(10000000);

      } else  //if the vehicl is not in the same section of the parking lot
      {
        if (counter_angle_Left == 1)  //ClockWise moving direction
        {
          GG();
        } else  //CounterClockWise moving direction
        {
          RR();
        }
      }
    }
    }
  }

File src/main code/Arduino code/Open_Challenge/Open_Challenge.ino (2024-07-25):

#include <ArduinoQueue.h> // Library for creating and managing queues
#include <NewPing.h> // Library for controlling ultrasonic sensors
#include <Servo.h> // Library for controlling servo motors
#include <math.h> // Math library for mathematical functions
#include <MPU6050_light.h> // Library for MPU6050 accelerometer and gyroscope

// Define pin numbers for ultrasonic sensors
#define TRIGGER_PIN_LEFT1  40
#define ECHO_PIN_LEFT1  41
#define TRIGGER_PIN_LEFT2  29
#define ECHO_PIN_LEFT2  28
#define TRIGGER_PIN_RIGHT1  32
#define ECHO_PIN_RIGHT1  33
#define TRIGGER_PIN_RIGHT2  48
#define ECHO_PIN_RIGHT2  49
#define TRIGGER_PIN_FRONT 44
#define ECHO_PIN_FRONT  45
#define TRIGGER_PIN_DIAG_RIGHT 52
#define ECHO_PIN_DIAG_RIGHT 53
#define TRIGGER_PIN_DIAG_LEFT 30
#define ECHO_PIN_DIAG_LEFT 31
#define TRIGGER_PIN_BACK 24
#define ECHO_PIN_BACK 25
#define TRIGGER_PIN_BACKLEFT 3
#define ECHO_PIN_BACKLEFT 4
#define TRIGGER_PIN_BACKRIGHT 27
#define ECHO_PIN_BACKRIGHT 26

// Define constants
#define MAX_DISTANCE 300 // Maximum distance to ping (in centimeters)
#define RIGHT_EN 35 // Enable pin for right motor
#define LEFT_EN 34 // Enable pin for left motor
#define RIGHT_PWM 3 // PWM pin for right motor speed control
#define LEFT_PWM 2 // PWM pin for left motor speed control

// Initialize MPU6050, Servos, and NewPing objects
MPU6050 mpu(Wire); // Create MPU6050 object for IMU
Servo leftServo, rightServo; // Create Servo objects for left and right steering
NewPing sonarLeft1(TRIGGER_PIN_LEFT1, ECHO_PIN_LEFT1, MAX_DISTANCE); // Initialize ultrasonic sensor for left1
NewPing sonarLeft2(TRIGGER_PIN_LEFT2, ECHO_PIN_LEFT2, MAX_DISTANCE); // Initialize ultrasonic sensor for left2
NewPing sonarRight1(TRIGGER_PIN_RIGHT1, ECHO_PIN_RIGHT1, MAX_DISTANCE); // Initialize ultrasonic sensor for right1
NewPing sonarRight2(TRIGGER_PIN_RIGHT2, ECHO_PIN_RIGHT2, MAX_DISTANCE); // Initialize ultrasonic sensor for right2
NewPing sonarFront(TRIGGER_PIN_FRONT, ECHO_PIN_FRONT, MAX_DISTANCE); // Initialize ultrasonic sensor for front
NewPing sonarDiagRight(TRIGGER_PIN_DIAG_RIGHT, ECHO_PIN_DIAG_RIGHT, MAX_DISTANCE); // Initialize ultrasonic sensor for diagonal right
NewPing sonarDiagLeft(TRIGGER_PIN_DIAG_LEFT, ECHO_PIN_DIAG_LEFT, MAX_DISTANCE); // Initialize ultrasonic sensor for diagonal left
NewPing sonarBack(TRIGGER_PIN_BACK, ECHO_PIN_BACK, MAX_DISTANCE); // Initialize ultrasonic sensor for back
NewPing sonarBackLeft(TRIGGER_PIN_BACKLEFT, ECHO_PIN_BACKLEFT, MAX_DISTANCE); // Initialize ultrasonic sensor for back left
NewPing sonarBackRight(TRIGGER_PIN_BACKRIGHT, ECHO_PIN_BACKRIGHT, MAX_DISTANCE); // Initialize ultrasonic sensor for back right

// Variables for storing sensor readings
float distanceLeft1, distanceLeft2, distanceRight1, distanceRight2;
float distanceFront, distanceDiagRight, distanceDiagLeft;
float distanceBack, distanceBackLeft, distanceBackRight;

// Setup function to initialize sensors and servos
void setup() {
  Serial.begin(9600); // Start serial communication at 9600 baud rate
  
  // Initialize servos
  leftServo.attach(9); // Attach left servo to pin 9
  rightServo.attach(10); // Attach right servo to pin 10

  // Initialize MPU6050
  Wire.begin(); // Begin I2C communication
  mpu.begin(); // Initialize MPU6050
  mpu.calcGyroOffsets(true); // Calibrate gyro offsets and wait for it to be done

  // Set motor control pins as outputs
  pinMode(RIGHT_EN, OUTPUT);
  pinMode(LEFT_EN, OUTPUT);
  pinMode(RIGHT_PWM, OUTPUT);
  pinMode(LEFT_PWM, OUTPUT);
}

// Function to read distances from all ultrasonic sensors
void readDistances() {
  distanceLeft1 = sonarLeft1.ping_cm(); // Read distance from left1 sensor
  distanceLeft2 = sonarLeft2.ping_cm(); // Read distance from left2 sensor
  distanceRight1 = sonarRight1.ping_cm(); // Read distance from right1 sensor
  distanceRight2 = sonarRight2.ping_cm(); // Read distance from right2 sensor
  distanceFront = sonarFront.ping_cm(); // Read distance from front sensor
  distanceDiagRight = sonarDiagRight.ping_cm(); // Read distance from diagonal right sensor
  distanceDiagLeft = sonarDiagLeft.ping_cm(); // Read distance from diagonal left sensor
  distanceBack = sonarBack.ping_cm(); // Read distance from back sensor
  distanceBackLeft = sonarBackLeft.ping_cm(); // Read distance from back left sensor
  distanceBackRight = sonarBackRight.ping_cm(); // Read distance from back right sensor
}

// Function to set motor speeds
void setMotorSpeed(int leftSpeed, int rightSpeed) {
  analogWrite(LEFT_PWM, leftSpeed); // Set speed for left motor
  analogWrite(RIGHT_PWM, rightSpeed); // Set speed for right motor
}
void loop() {
    // Main loop where sensor readings and control logic are processed
    sensorRead(); // Update sensor readings from all sensors

    if (servoSet) {
        rightServo.write(servoPosRight); // Set the right servo position
        leftServo.write(servoPosLeft); // Set the left servo position
        servoSet = false; // Reset the servoSet flag
        mpu.update(); // Update MPU6050 sensor data
        gyroRefMpu = mpu.getAngleZ(); // Reference the Z-axis angle from the MPU6050
    }

    // Main navigation and wall avoidance logic
    if (distanceFront > 90) {  // If front distance is greater than 90 cm
        if (realDistanceLeft < setPoint) {
            runMotor(speedBeforeTurn); // Move forward at speed before turn
            controlDistanceLeft(realDistanceLeft); // Adjust left distance
        }

        if (realDistanceRight < setPoint) {
            runMotor(speedBeforeTurn); // Move forward at speed before turn
            controlDistanceRight(realDistanceRight); // Adjust right distance
        }

        if (realDistanceLeft > setPoint && realDistanceRight > setPoint && angleCounterLeft == 1) {
            runMotor(speedCurrent); // Move forward at current speed
            if (angleCounterLeft > 0) {
                angle += angleCalc(distanceLeft1, distanceLeft2) * 180 / acos(-1); // Calculate and accumulate angle
                angleCounterLeft--; // Decrement angle counter
            }
            if (angleCounterLeft == 0) {
                gyroRefMpu += angle / 5; // Adjust gyro reference
                angleCounterLeft = -1; // Reset angle counter
                angle = 0; // Reset angle
            }
            mpu.update(); // Update MPU6050 sensor data
            pidAngle(mpu.getAngleZ()); // PID control based on current angle
        }
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

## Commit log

2024-07-25 Rename base.STL to Ultrasonic Sensor Holder Base.STL
    [Ultrasonic Sensor Holder Base.STL]
2024-07-25 Rename hexa.STL to Hexagonal Rod.STL
    [Hexagonal Rod.STL]
2024-07-25 Rename hexa.SLDPRT to Hexagonal Rod.SLDPRT
    [Hexagonal Rod.SLDPRT]
2024-07-25 Rename base.SLDPRT to Ultrasonic Sensor Holder Base.SLDPRT
    [Ultrasonic Sensor Holder Base.SLDPRT]
